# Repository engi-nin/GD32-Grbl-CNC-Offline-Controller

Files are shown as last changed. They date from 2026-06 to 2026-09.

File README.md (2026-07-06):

# GD32-Grbl-CNC-Offline-Controller

offline_F

## 概要
GD32F303VCT6を搭載した、ＧＲＢＬ‐ＣＮＣ向けのオフライン制御端末用ファームウェアです。

＊＊注意＊＊
GD32F303VCT6以外のマイコンやＴＦＴの種類によって正常に動かない可能性があります

GRBL1.1用のコントローラーとシリアル通信を行い、PCレスでの操作を実現します。
主な操作
ＸＹＺ軸のＪＯＧ操作、0.01,0.1,1,10mmの４段階、速度は５０ステップで５０～５００mm／min、スピンドルＯＮ、ＯＦＦ
＄コマンド出力、$H,$X$$,$C,$SLP,$G,$10,Ctrl+X
ＳＤカードからのファイル読み出し、Ｇコード出力、一時停止機能付き
ＸＹＺのゼロセット、ゼロ位置移動
プローブ動作、Ｚ、Ｘ＋、Ｘ－、Ｙ＋、Ｙ－、左下コーナーゼロセット、穴中心ゼロセット、軸中心ゼロセット

## ハードウェア仕様
- **MCU:** GD32F303VCT6
- **Display:** 1.8 inch TFT (ST7735)
- **Interface:** SPI / UART / SD Card

offline_B

### ピンアサイン（主要部分）
| 機能 | ピン番号 | 備考 |
タクトスイッチ
PB10(47)[OK]
PC4(33)[Y+]
PC6(63)[Y-]
PB12(51)[X+]
PB11(48)[X-]
PC5(35)[EXIT]
PB6(92)[Z+]
PB5(91)[Z-]

ＵＳＢ
PA11(70)USBDM
PA12(71)USBDP

SD SLOT
MOSI PB15(54)　　
MISO PB14(53) 　　
SD_SCK  PB13(52)  
CS_SLOT_A PC7(64)　　microSD
CS_SLOT_B PD12(59) 　ＳＤ

シリアル端子
PA2(25)USART_1TX
PA3(26)USART_1RX

(液晶表示はビットバンニングで動作確認できている)
1.8inchTFT

#define TFT_CS   PD7(88)　　チップセレクト
#define TFT_DC   PD11(58)　　データＨ／コマンドＬ切替
#define TFT_RST  PE1(90)　　リセット
#define TFT_WR   PD5(86)　　書き込み信号
#define TFT_RD   PD4(85)　　読み出し信号
#define TFT_BL   PD13(60) // バックライト
// データバス (D0-D7) の変則配置をここで定義
#define D0_PIN   PD14(61)　データビット０
#define D1_PIN   PD15(62)　データビット１
#define D2_PIN   PD0(81)　　データビット２
#define D3_PIN   PD1(82)　　データビット３
#define D4_PIN   PE7(38)　　データビット４
#define D5_PIN   PE8(39)　　データビット５
#define D6_PIN   PE9(40)　　データビット６
#define D7_PIN   PE10(41)　　データビット７

## 開発環境
- PlatformIO
- GD32 Arduino Core (または SPL)

## 使い方
1. PlatformIOでこのフォルダを開きます。
2. `platformio.ini` の設定を確認してください。
3. ビルドしてターゲットボードに書き込みます。

https://youtu.be/XpaJLY-EAXQ?si=iFZQxmoBzAtlG87i

## ライセンス
MIT License

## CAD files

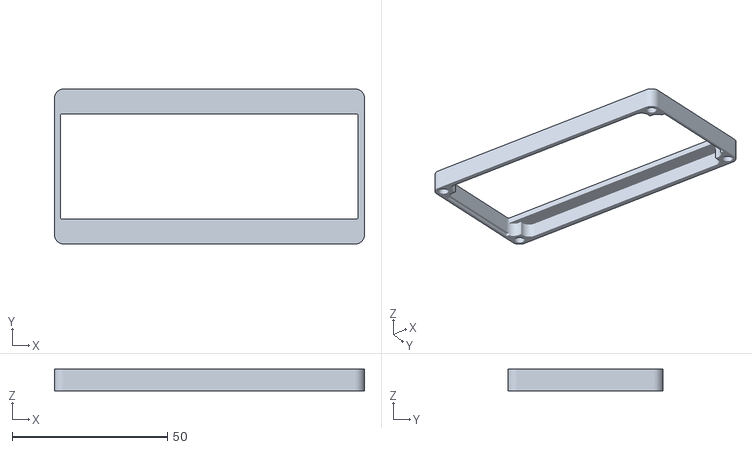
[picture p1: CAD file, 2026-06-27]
cad_data/upper case.stl
100.0 x 50.0 x 7.00

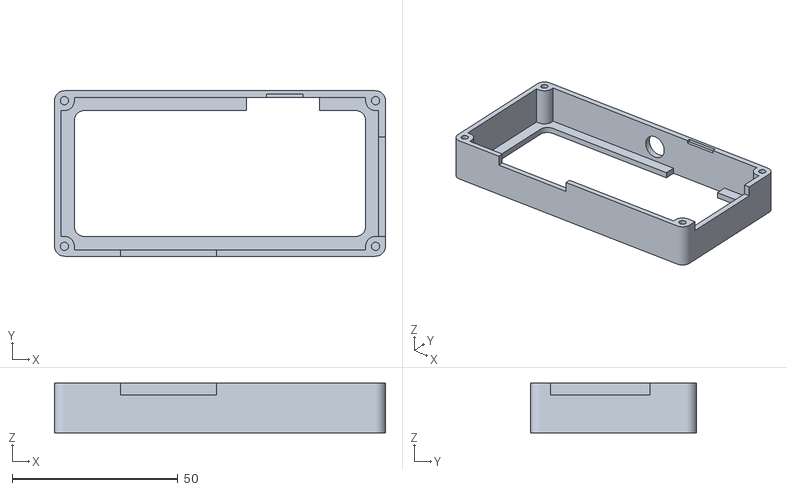
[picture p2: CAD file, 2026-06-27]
cad_data/under case.stl
100.0 x 50.0 x 15.0

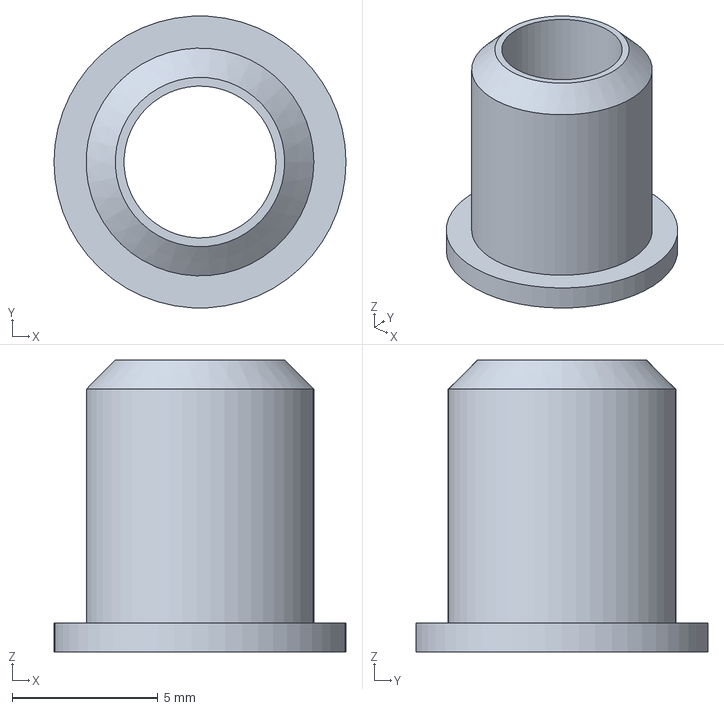
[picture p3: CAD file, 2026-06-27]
cad_data/cable_holder.FCStd
10.0 x 9.98 x 10.0 mm

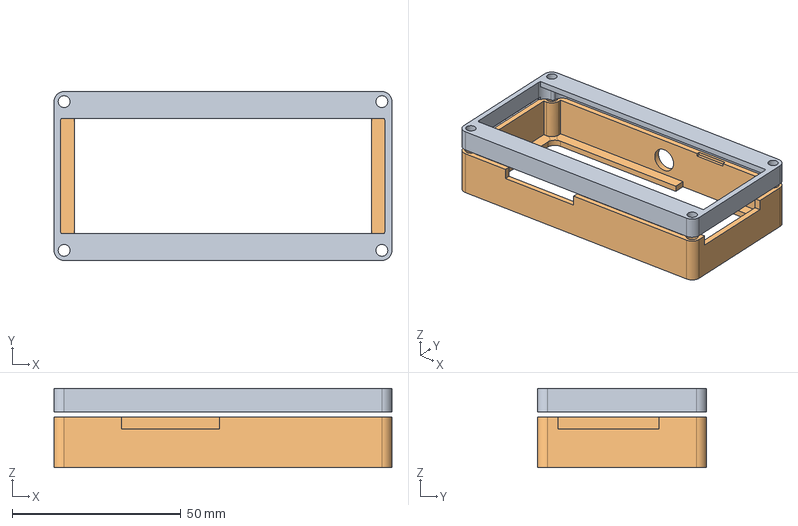
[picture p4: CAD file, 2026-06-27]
cad_data/offline_controller.FCStd
100.0 x 50.0 x 23.5 mm
upper case
under case

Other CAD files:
cad_data/cable_holder.stl

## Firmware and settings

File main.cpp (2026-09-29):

#include <Arduino.h>
#include "config.h"
#include "tft_control.h"
#include "switch_control.h"
#include "grbl_serial.h"
#include "sd_control.h"
#include <SPI.h>
#include <SdFat.h>
#include "probe_macro.h"


// --- 設定・定数 ---
#define BTN_W 20      // 標準の横幅
#define BTN_H 16      // 標準の高さ
#define BTN_R 5       // 角の丸み
#define BTN_Z_W 20    // Z軸などの細長いボタン用
#define ESC_BTN EXIT
#define OK_BTN OK
#define Y_PL   Y_UP // Ｙ＋
#define Y_DN   Y_DOWN  // Ｙ－
#define X_LF   X_DOWN  // Ｘ－
#define X_RT   X_UP  // Ｘ＋
#define Z_PL   Z_UP  // Ｚ＋
#define Z_DN   Z_DOWN  // Ｚ－
#define TFT_BL PD13
#define SD_CONFIG SdSpiConfig(PC7, SHARED_SPI, SD_SCK_MHZ(10), &softSpi)


// --- インスタンス ---
TFTControl tft;
SwitchControl sw;

SdFat fatFs;
FsFile currentGCodeFile;
SoftSpiDriver<PB14, PB15, PB13> softSpi;

//enum DisplayMode { MODE_MENU,MODE_JOG, MODE_SD, MODE_SETTING ,MODE_SENDING,MODE_PROBE};

struct JogButton {
    Button pin;        // スイッチのピン番号
    String axis;    // 軸名 ("X", "Y", "Z")
    float direction; // 向き (1.0 または -1.0)
    const char* label; // ボタンの表示名
    int16_t x, y, w, h; // 描画位置
    uint16_t color;  // 通常時の色
    int stateIdx;// lastStates配列の何番目を使うか
};

HardwareSerial SerialGrbl(PA3, PA2);

DisplayMode currentMode = MODE_MENU;

bool lastStates[6] = {false, false, false, false, false, false};
bool escLastState = false;
bool backLastState = false;
bool escIsBeingPressed = false;      // 今まさに押されているか
bool isEscLongTargetReached = false; // 長押し確定演出用
bool isFirstOpen = true; // 画面を開いた直後判定用
bool okIsBeingPressed = false;       // OKボタン状態
bool isSpindleOn = false;            // スピンドル状態
bool xUpLast = false, xDnLast = false;
bool yUpLast = false, yDnLast = false;
bool zUpLast = false, zDnLast = false;
bool xUpLastState = false;
bool xDnLastState = false;
bool yUpLastState = false;
bool yDnLastState = false; 
bool zUpLastState = false;
bool zDnLastState = false;
bool isSending = false;        // 送信中フラグ
bool isConfirming = false;
bool isStreaming = false;       // 送信中かどうかのフラグ
bool waitingForOk = false; // GRBLからの返答待ちフラグ
bool isWaitingInitialResponse = false; // 最初のリプライ待ちフラグ
bool isShowingConsole = false;
bool isMovingToZero = false; // 💡 ゼロ位置への移動中かどうかを保持するフラグ

uint32_t streamStartTime = 0;          // タイムアウト監視用
char lastError[32] = "";       // エラーメッセージ格納用
SdFile gcodeFile;              // 現在開いているGコードファイル
unsigned long escPressStartTime_ex = 0; // 押し始めた時刻
unsigned long escPressStartTime_xl = 0;
unsigned long escPressStartTime_xr = 0;
unsigned long escPressStartTime_zu = 0;
unsigned long escPressStartTime_zd = 0;

float moveDistance = 1.0;            // 現在の移動距離 (1mm, 10mmなど)
float curX, curY, curZ;
int moveSpeed = 100;                 // 初期送り速度 100
unsigned long okPressStartTime = 0;  // OKボタン用
uint32_t totalFileBytes = 0;    // ファイルの総サイズ
uint32_t sentFileBytes = 0;     // 送信済みのサイズ
char lastSentGCode[64] = "";    // 最後に送った行
char lastGrblResponse[64] = ""; // GRBLからの最後の返事
static char currentFileName[32]; // 選択されたファイル名を保持する配列
char lineBuffer[64]; // Gコード1行分を溜めるバッファ（CNCの1行は通常50文字程度なので64で十分です）
int lineIdx = 0;     // バッファのどこまで文字を入れたかを記録する添え字
int consoleLineY = 20; // ログの書き出し開始位置
static int consoleLineCount = 0; 

static int currentLogPage = 0;
static int totalCapturedLines = 0;
bool escHandled_ex = false;
bool escHandled_xl = false;
bool escHandled_xr = false;
bool escHandled_zu = false;
bool escHandled_zd = false;

int currentPage = 0;          // 現在のページ番号（0から開始）

// 設定項目の構造体定義
struct SettingItem {
    const char* name;    // 画面に表示する名前
    const char* command; // GRBLに送るコマンド
};
enum LogType { TYPE_ERROR, TYPE_ALARM, TYPE_HOLD, TYPE_DOOR, TYPE_INFO };

struct GrblLog {
    LogType type;
    int code;
    const char* msg; // メッセージの要約（任意）
};

static uint32_t lastUpdateMillis = 0;

// --- ここに項目を追加・削除するだけでメニューが増えます ---
const SettingItem SETTINGS[] = {
    {"Homing Start ($H)",     "$H"},
    {"Alarm Unlock ($X)",     "$X"},
    {"GrblConfig ($$)",     "$$"},
    {"Check Mode ($C)", "$C"},
    {"Sleep mode ($SLP)",    "$SLP"},
    {"Status Read ($G)",     "$G"},
    {"<WPos:> ($10=0)",       "$10=0"},   
    {"<MPos:> ($10=1)",         "$10=1"},     
    {"Soft Reset (Ctrl+X)",   "SoftRESET"}  // 特殊処理用にキーワードを定義
};

// 項目の総数を自動計算
const int TOTAL_SETTINGS = sizeof(SETTINGS) / sizeof(SETTINGS[0]);
String grblResponse = "";    // 受信した返答を格納
bool pendingResponse = false; // 返答待ちフラグ

int selectedIndex = 0;       // 現在選択されている番号
bool enterLastState = false; // 決定ボタンの状態保存用
bool upLastState    = false; // 上ボタンの状態保存用
bool downLastState  = false; // 下ボタンの状態保存用

extern void rawUartPrint(USART_TypeDef *uart, const char* s);

extern void rawUartWriteChar(USART_TypeDef *uart, char c);
extern void rawUartFlush(USART_TypeDef *uart);
extern bool rawUartAvailable(USART_TypeDef *uart);
extern char rawUartReadChar(USART_TypeDef *uart);
extern int rawUartRead(USART_TypeDef *uart);
extern void sendByte(uint8_t b);

void drawJogUI();
void drawSDFileListUI();
void drawMenuUI();
void drawSettingUI();
void updateStatusDisplay();
void updateDebugConsole(String msg);
bool startGCodeStream(const char* filename);
void ConsoleLog(const char* log, uint16_t color, int16_t x, int16_t y);
void drawProbeUI();
static float countX = 0.00f;
static float countY = 0.00f;
static float countZ = 0.00f;
// 送信を許可するコマンドのリスト（ホワイトリスト）
const char* whiteList[] = {
    "G0", "G1", "G2", "G3", "G17", "G20", "G21", "G90", "G91", "G54",
    "M2","M3", "M5", "M8", "M9", "M30", "S", "F", "$"
};
void stopGCodeStream();
bool isAllowed(const char* line);
void GrblCurrentPos();
bool isPaused = false;
static uint32_t lastOkTime = 0;

// ボタンの「役割」を定義
enum ButtonType {
    BTN_PRIMARY,   // 標準ボタン
    BTN_ENABLED,    // 決定ボタン
    BTN_SEND,   // 完了・実行
    BTN_DISABLED   // 無効状態（グレー）
};

// 色の管理用構造体
struct ButtonStyle {
    uint16_t body;
    uint16_t text;
};

// 役割に応じた色の設定（ここで一元管理！）
ButtonStyle getStyle(ButtonType type) {
    switch (type) {
        case BTN_PRIMARY:  return {0x64D9, 0xFFFF};
        case BTN_ENABLED:  return {0xF800, 0xFFFF};
        case BTN_SEND:     return {0xFFE0, 0xFFFF};
        case BTN_DISABLED: return {0x01AD, 0xFFFF}; // ダークグレーとライトグレー
        default:           return {0xFFFF, 0x0000};
    }
}

// GRBLから取得した実座標格納用
float prbX = 0.0f, prbY = 0.0f, prbZ = 0.0f;

// 内径測定用のステップ管理と一時記憶
static float center_X1 = 0.0f;
static float center_X2 = 0.0f;
static float center_Y1 = 0.0f;
static float center_Y2 = 0.0f;
static float target_X_Center = 0.0f;
static float target_Y_Center = 0.0f;

// ─── ファイルスコープ（またはグローバル）で維持する変数群 ───
static float macroStart_X = 0.0f;
static float macroStart_Y = 0.0f;
static float macroStart_Z = 0.0f;
static float calculated_X_Center = 0.0f;
static float calculated_Y_Center = 0.0f;

// 各測定ステップで取得するプローブ座標（PRB応答から抽出）

static float center_Z1 = 0.0f;
static float center_Z2 = 0.0f;

static float corner_X1 = 0.0f;
static float corner_Y1 = 0.0f;


// ─── 選択型メニュー用の管理変数 ───
int menuCursorX = 0; // 0:左列(アクション), 1:右列(モード遷移)
int menuCursorY = 0; // 0〜2行目 (左:X/Y, Z, 空き / 右:JOG, SD, SETTING, Probe)

// 長押しポップアップ管理用
bool isPopupActive = false;
int popupSelection = 0; // ポップアップ内の選択肢 (0: ゼロセット, 1: ゼロへ移動, 2: キャンセル)
int targetAxisMode = 0; // 0: X/Y軸, 1: Z軸

// ボタンの配置定義を扱いやすくするための構造体
struct MenuButtonPos {
    int x; int y; int w; int h;
    const char* label;
};

// 画面のボタン配置と完全に同期した配列
static const MenuButtonPos leftMenuBtns[2] = {
    {5,  38, 70, 18, "X/Y ZERO"},
    {5, 110, 70, 18, "Z ZERO"} 
};

static const MenuButtonPos rightMenuBtns[4] = {
    {85,  38, 65, 18, "JOG MODE"},
    {85,  62, 65, 18, "SD FILES"},
    {85,  85, 65, 18, "SETTINGS"},
    {85, 110, 65, 18, "Probe"}
};

// 内径探査のステート追跡用
enum DummyState { STATE_NONE, STATE_X1, STATE_X2, STATE_Y1, STATE_Y2,STATE_Z1,STATE_Z2,STATE_CR_X,STATE_CR_Y };

static const char* dummyZ_P1  = "D_Z_P1";
static const char* dummyZ_P2  = "D_Z_P2";

static const char* dummyX_P   = "D_X_P";
static const char* dummyX_M   = "D_X_M";
static const char* dummyY_P   = "D_Y_P";
static const char* dummyY_M   = "D_Y_M";

static const char* dummyCR_X1 = "D_CR_X1"; // コーナー用：X探査
static const char* dummyCR_X2 = "D_CR_X2"; // コーナー用：X退避(絶対座標)
static const char* dummyCR_Y1 = "D_CR_Y1"; // コーナー用：Y回り込み位置(絶対座標)
static const char* dummyCR_Y2 = "D_CR_Y2"; // コーナー用：ワーク前方に進む(絶対座標)
static const char* dummyCR_Y3 = "D_CR_Y3"; // コーナー用：Y探査
static const char* dummyCR_G10= "D_CR_G10";// コーナー用：最終座標設定＆安全退避

static const char* dummyIN_X1 = "D_IN_X1";
static const char* dummyIN_X2 = "D_IN_X2";
static const char* dummyIN_CX = "D_IN_CX";
static const char* dummyIN_Y1 = "D_IN_Y1";
static const char* dummyIN_Y2 = "D_IN_Y2";
static const char* dummyIN_CY = "D_IN_CY";

static const char* dummyOUT_X1 = "D_OUT_X1";
static const char* dummyOUT_X2 = "D_OUT_X2";
static const char* dummyOUT_X3 = "D_OUT_X3";
static const char* dummyOUT_X4 = "D_OUT_X4";
static const char* dummyOUT_X5 = "D_OUT_X5";
static const char* dummyOUT_Y1 = "D_OUT_Y1";
static const char* dummyOUT_Y2 = "D_OUT_Y2";
static const char* dummyOUT_Y3 = "D_OUT_Y3";
static const char* dummyOUT_Y4 = "D_OUT_Y4";
static const char* dummyOUT_Y5 = "D_OUT_Y5";
static const char* dummyOUT_FIN= "D_OUT_FIN";

bool isEditingWorkDia = false;  // ★追加：ワーク径のポップアップ表示/編集フラグ
int pendingProbeItem = 0;       // ★追加：ポップアップを開いた元のプローブ項目を一時保持
float workDiameter = 50.0f;     // ★追加：ワーク/穴の直径 (初期値)


// ボタンのラベルを描画するヘルパー関数
void drawButtonLabel(int16_t x, int16_t y, int16_t w, int16_t h, const char* label, uint16_t textColor) {
    tft.setTextColor(textColor);
    tft.setTextSize(1); 

    // --- 中央配置のための計算 ---
    // 標準フォント（Size 1）は 1文字 = 幅6px, 高さ8px です
    int16_t textWidth = strlen(label) * 6;
    int16_t textHeight = 8;

    // ボタンの幅(w)から文字の幅を引いて半分にすることで、正確に中央へ配置
    int16_t textX = x + (w - textWidth) / 2;
    int16_t textY = y + (h - textHeight) / 2;

    // もし計算結果がマイナス（ボタンより文字が長い）になった場合の安全策
    if (textX < x) textX = x + 2; 

    tft.setCursor(textX, textY);
    tft.print(label);
}
//ボタン描画
void drawMyButton(int16_t x, int16_t y, int16_t w, int16_t h, const char* label, ButtonType type) {
    // getStyleに引数で受け取った「type」を渡す
    ButtonStyle style = getStyle(type);
    
    tft.fillRoundRect(x, y, w, h, BTN_R, style.body);
    drawButtonLabel(x, y, w, h, label, style.text);
}
//起動時のロゴ画面
void drawOpeningScreen() {
    tft.fillScreen(0x0000); // 黒背景
    
    tft.setTextSize(2);
    
    tft.setTextColor(0x065F);
    tft.setCursor(60, 15);
    tft.print(F("Grbl"));
    tft.setCursor(40, 40);
    tft.setTextColor(0xEFFD);
    tft.print(F("OFFLINE"));
    tft.setCursor(20, 65);
    tft.print(F("CONTROLLER"));

    tft.setTextColor(0xFFFF);
    tft.setTextSize(1);
    tft.setCursor(60, 90);
    tft.print(F(VERSION_STR));
    
    //tft.update();
    delay(3000); // 2秒間ロゴを表示
}
//メニューコンソール用エラーコード表示データ
void drawDetailedLog(const char* rawRes, int16_t x, int16_t y) {
    LogType type = TYPE_INFO;
    int code = -1;
    uint16_t color = 0xFFFF; // デフォルト白
    String displayMsg = "";

    // --- 1. 種類の判定と解析 ---
    if (strstr(rawRes, "error:") != NULL) {
        type = TYPE_ERROR;
        code = atoi(rawRes + 6); // "error:" の後を取得
        color = 0xF800; // 赤
        displayMsg = "ERROR [" + String(code) + "]: ";
    } 
    else if (strstr(rawRes, "ALARM:") != NULL) {
        type = TYPE_ALARM;
        code = atoi(rawRes + 6);
        color = 0xFB20; // オレンジ
        displayMsg = "ALARM [" + String(code) + "]: ";
    }
    else if (strstr(rawRes, "Hold:") != NULL) {
        type = TYPE_HOLD;
        code = atoi(rawRes + 5);
        color = 0xFFE0; // 黄
        displayMsg = "HOLD [" + String(code) + "]: ";
    }
    else if (strstr(rawRes, "Door:") != NULL) {
        type = TYPE_DOOR;
        code = atoi(rawRes + 5);
        color = 0x07FF; // 水色
        displayMsg = "DOOR [" + String(code) + "]: ";
    }

    // --- 3. TFTへ表示 ---
    if (displayMsg != "") {
        ConsoleLog(displayMsg.c_str(), color, x, y);
    }
}
//コンソールエラー表示
void ConsoleLog(const char* log, uint16_t color, int16_t x, int16_t y) {
    tft.fillRect(x,y,150,8,0x0000);
    tft.setTextSize(1);
    tft.setTextColor(color); 
    tft.setCursor(x, y); 
    tft.print(log);
}
//メニュー画面ＸＹＺ描画
void updateMenuCoordinates() {
    // 通信確認
    bool isTimeout = (millis() - lastUpdateMillis > 1000);
    uint16_t txtColor = isTimeout ? 0xF800 : 0xFFFF;

    // X軸
    tft.setCursor(28, 65);
    tft.setTextColor(txtColor, 0x0000);
    if (!isTimeout) tft.print(String(grbl.currentX, 2)); 
    else tft.print("  ?.??");

    // Y軸
    tft.setCursor(28, 80);
    tft.setTextColor(txtColor, 0x0000);
    if (!isTimeout) tft.print(String(grbl.currentY, 2)); 
    else tft.print("  ?.??");

    // Z軸
    tft.setCursor(28, 95);
    tft.setTextColor(txtColor, 0x0000);
    if (!isTimeout) tft.print(String(grbl.currentZ, 2)); 
    else tft.print("  ?.??");
}
//ＸＹＺ位置取得
void GrblCurrentPos(int16_t x,int16_t y){
    grbl.sendByte('?');
    grbl.update(); 
        while (grbl.grblavailable()) {
        const char* res = grbl.getNextLine();
        
        if (res[0] == '<') {
            // ★重要：ここで解析関数を呼ぶ
            if (grbl.parseGrblResponse(res)) {
                lastUpdateMillis = millis(); // 座標解析に成功したらタイマーリセット
            }
        } 
        else if (strcmp(res, "ok") != 0) {
            // ok 以外の重要なメッセージ（error等）があればログへ
          drawDetailedLog(res,x,y);  
        }
    }
}
// 2. メインメニュー画面
void drawMenuUI() {
    grbl.clearBuffer();

    tft.fillScreen(0x0000); // 背景ブラック
    
    tft.setCursor(40, 5);
    tft.setTextColor(0xFFFF); // ホワイト
    tft.println(F("[ Main MENU ]"));
     
    // --- 座標表示エリアの背景と枠線 ---
    tft.fillRect(5, 20, 150, 15, 0x0000); // レスポンスコンソール背景
    tft.drawRect(5, 20, 150, 15, 0xFFFF); // レスポンスコンソール白い枠線
    tft.drawRect(5, 60, 75, 47, 0xFFFF); // ＸＹＺ Ａｘｉｓ白枠

    tft.setTextSize(1);
    tft.setTextColor(0xFFFF);
    
    GrblCurrentPos(10, 25);
    
    // X軸
    tft.setCursor(10, 65);
    tft.setTextColor(0xFFFF, 0x0000);
    tft.print("X:");
    tft.setCursor(28, 65);
    tft.print(String(grbl.currentX, 2));

    // Y軸
    tft.setCursor(10, 80);
    tft.setTextColor(0xFFFF, 0x0000);
    tft.print("Y:");
    tft.setCursor(28, 80);
    tft.print(String(grbl.currentY, 2));

    // Z軸
    tft.setCursor(10, 95);
    tft.setTextColor(0xFFFF, 0x0000);
    tft.print("Z:");
    tft.setCursor(28, 95);
    tft.print(String(grbl.currentZ, 2));
   
    // ==================================================
    // --- 十字キー選択対応：左列ボタンの配置 (menuCursorX == 0) ---
    // ==================================================
    for (int i = 0; i < 2; i++) {
        // ポップアップが閉じており、且つカーソルが左列(0)のi行目にある場合は ENABLED、それ以外は PRIMARY
        ButtonType btnType = (!isPopupActive && menuCursorX == 0 && menuCursorY == i) ? BTN_PRIMARY : BTN_DISABLED;
        
        drawMyButton(
            leftMenuBtns[i].x, 
            leftMenuBtns[i].y, 
            leftMenuBtns[i].w, 
            leftMenuBtns[i].h, 
            leftMenuBtns[i].label, 
            btnType
        );
    }

    // ==================================================
    // --- 十字キー選択対応：右列ボタンの配置 (menuCursorX == 1) ---
    // ==================================================
    for (int i = 0; i < 4; i++) {
        // ポップアップが閉じており、且つカーソルが右列(1)のi行目にある場合は ENABLED、それ以外は PRIMARY
        ButtonType btnType = (!isPopupActive && menuCursorX == 1 && menuCursorY == i) ? BTN_PRIMARY : BTN_DISABLED;
        
        drawMyButton(
            rightMenuBtns[i].x, 
            rightMenuBtns[i].y, 
            rightMenuBtns[i].w, 
            rightMenuBtns[i].h, 
            rightMenuBtns[i].label, 
            btnType
        );
    }
   
    grbl.clearBuffer();
}
//メニュー画面のＺボタンのポップアップ描画
void drawZeroPopup(const char* title) {
    // ポップアップの外枠と背景
    tft.fillRect(15, 35, 130, 80, 0x0000); // 黒塗り潰し
    tft.drawRect(15, 35, 130, 80, 0xF800); // 赤い警告枠
    
    tft.setCursor(25, 42);
    tft.setTextColor(0xFFFF);
    tft.print(title);
    
    // 選択肢の描画
    const char* options[3] = {
        " 1. Zero Set (G10)",
        " 2. Move to Zero",
        " 3. Cancel"
    };
    
    for (int i = 0; i < 3; i++) {
        tft.setCursor(20, 60 + (i * 15));
        if (popupSelection == i) {
            tft.setTextColor(0x0000, 0xFFFF); // 反転表示（選択中）
        } else {
            tft.setTextColor(0xFFFF, 0x0000);
        }
        tft.println(options[i]);
    }
}
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
void loop() {
   
    switch (currentMode) {
        case MODE_MENU:    handleMenuButtons();    break;
        case MODE_JOG:     handleJogButtons();    break;
        case MODE_SD:      handleSDButtons();     break;
        case MODE_SETTING: handleSettingButtons(); break;
        case MODE_SENDING: handleSendingMode();    break;
        case MODE_PROBE:   handleProbeButtons(); break;
    }
    handleProbeStreaming();
}

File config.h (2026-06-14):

#ifndef CONFIG_H
#define CONFIG_H

#include <Arduino.h>

// =================================================================
// 1. システム・バージョン情報
// =================================================================
const char* const VERSION_STR = "Ver 1.0";

// =================================================================
// 2. 物理ピン配置 (Pin Assignments)
// =================================================================
#define TFT_BL         PD13    // TFT バックライトピン

// ソフトSPI (SDカード用) ピン配置
#define SD_MOSI_PIN    PB15
#define SD_MISO_PIN    PB14
#define SD_SCK_PIN     PB13
#define SD_CS_PIN      PC7

// GRBLシリアル通信ピン (HardwareSerial)
#define GRBL_TX_PIN    PA2
#define GRBL_RX_PIN    PA3

// =================================================================
// 3. キー入力・ボタンマッピング設定
// =================================================================
#define ESC_BTN        EXIT    // 物理スイッチのキャンセル割り当て
#define OK_BTN         OK      // 物理スイッチの決定割り当て

#define Y_PL           Y_UP    // Ｙ＋方向ボタン
#define Y_DN           Y_DOWN  // Ｙ－方向ボタン
#define X_LF           X_DOWN  // Ｘ－方向ボタン
#define X_RT           X_UP    // Ｘ＋方向ボタン
#define Z_PL           Z_UP    // Ｚ＋方向ボタン
#define Z_DN           Z_DOWN  // Ｚ－方向ボタン

const int LONG_PRESS_MS = 800;        // 長押しと判定する時間（ミリ秒）
const unsigned long LONG_PRESS_TIME = 1000; // ポップアップ等での長押し確定時間

// =================================================================
// 4. UI・グラフィックデザイン定数
// =================================================================
#define BTN_W          20      // 標準のボタン横幅
#define BTN_H          16      // 標準のボタン高さ
#define BTN_R          5       // ボタン角の丸み
#define BTN_Z_W        20      // Z軸等の細長いボタン用横幅

const int ITEMS_PER_PAGE = 10; // SDカード等の1画面あたり最大表示数
const int lineHeight     = 10; // コンソールログの1行の高さ
const int logStartX      = 5;  // ログの描画開始X座標
const int logStartY      = 18; // ログの描画開始Y座標
enum DisplayMode { MODE_MENU,MODE_JOG, MODE_SD, MODE_SETTING ,MODE_SENDING,MODE_PROBE};
// =================================================================
// 5. CNC・プローブ（探査）初期設定パラメータ
// =================================================================
const float DEFAULT_TOOL_DIAMETER = 3.0f;  // デフォルトのツール径 (mm)
const float DEFAULT_PROBE_FEEDRATE = 40.0f; // タッチ探査時のフィードスピード (F)

// 外径・内径探査の安全逃げ・潜り設定
const float DEFAULT_OUTER_CLEARANCE_X = 40.0f; // 開始点から左右に逃げる距離 (mm)
const float DEFAULT_OUTER_CLEARANCE_Y = 40.0f; // 開始点から前後に逃げる距離 (mm)
const float DEFAULT_OUTER_PROBE_DEPTH = 15.0f; // タッチのためにZ軸が潜る深さ (mm)


#endif // CONFIG_H

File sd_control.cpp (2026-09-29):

#include <SdFat.h>
#include "sd_control.h"

extern SoftSpiDriver<PB14, PB15, PB13> softSpi; 

SDControl::SDControl() : _fileCount(0), _selectedIndex(0), _currentSlot(SLOT_A), _isInitializedA(false), _isInitializedB(false) {
    _currentSD = &_sdA; 
}

void SDControl::releaseAllSlots() {
    pinMode(CS_SLOT_A, OUTPUT);
    pinMode(CS_SLOT_B, OUTPUT);
    digitalWrite(CS_SLOT_A, HIGH);
    digitalWrite(CS_SLOT_B, HIGH);
}
    
void SDControl::activateBus() {
    releaseAllSlots();
    delayMicroseconds(10); 
}

bool SDControl::_initBus(SDSlot slot, bool forceReinit) {
    _currentSD = (slot == SLOT_A) ? &_sdA : &_sdB;

    // ファイルが開いているなら閉じる
    if (_currentFile.isOpen()) {
        _currentFile.close();
    }

    releaseAllSlots();
    delay(20); 

    uint8_t targetPin = (slot == SLOT_A) ? CS_SLOT_A : CS_SLOT_B;
 
    // 安定性を考慮し、2MHzで初期化
    SdSpiConfig config(targetPin, SHARED_SPI, SD_SCK_MHZ(2), &softSpi);
    
    // 毎回 .end() を呼んでバスの競合を防ぐ
    _currentSD->end();
    
    // フラグでスキップせず、毎回確実に begin() を通す
    // (SdFatの begin() は安全に再初期化を行ってくれます)
    if (!_currentSD->begin(config)) {
        if (slot == SLOT_A) _isInitializedA = false;
        else _isInitializedB = false;
        return false; 
    }

    if (slot == SLOT_A) _isInitializedA = true;
    else _isInitializedB = true;

    _currentSlot = slot;
    return true;
}

bool SDControl::scanFiles(SDSlot slot) {
    _fileCount = 0;
    _selectedIndex = 0;
    for (int i = 0; i < MAX_FILES; i++) _fileList[i][0] = '\0';

    // スロットを切り替えて初期化
    if (!_initBus(slot, false)) {
        return false; 
    }

    FsFile root;
    // 修正: _currentSD->open() を使用してルートディレクトリを開く
    if (!root.open(_currentSD->vol(), "/", O_RDONLY)) { 
        // ボリューム指定でのオープンが失敗する場合のフォールバック
        if (!root.open(_currentSD, "/", O_RDONLY)) {
            return false;
        }
    }

    FsFile entry;
    while (entry.openNext(&root, O_RDONLY)) {
        if (!entry.isDir() && !entry.isHidden()) {
            entry.getName(_fileList[_fileCount], sizeof(_fileList[0]));
            _fileCount++;
        }
        entry.close();
        if (_fileCount >= MAX_FILES) break;
    }
    root.close();

    if (_fileCount == 0) {
        cid_t cid;
        return _currentSD->card()->readCID(&cid);
    }
    return true;
}

void SDControl::selectNext() {
    if (_fileCount > 0) _selectedIndex = (_selectedIndex + 1) % _fileCount;
}

void SDControl::selectPrev() {
    if (_fileCount > 0) _selectedIndex = (_selectedIndex - 1 + _fileCount) % _fileCount;
}

char* SDControl::getSelectedFileName() {
    if (_fileCount == 0) return nullptr;
    return _fileList[_selectedIndex];
}

uint32_t SDControl::getFileSize() {
    if (_currentFile.isOpen()) {
        return _currentFile.size();
    }
    return 0;
}

bool SDControl::openFile(const char* filename) {
    if (_currentFile.isOpen()) {
        _currentFile.close();
    }
    
    // スロットのバスと初期化状態を確認
    if (!_initBus(_currentSlot, false)) return false;

    // 修正: _currentSD のオブジェクトから直接 open する
    _currentFile = _currentSD->open(filename, O_RDONLY);
    
    return _currentFile.isOpen();
}

void SDControl::closeCurrent() {
    if (_currentFile.isOpen()) {
        _currentFile.close();
    }
}

const char* SDControl::getCurrentSlotName() {
    return (_currentSlot == SLOT_A) ? "Slot A" : "Slot B"; 
}

bool SDControl::switchSlot() {
    SDSlot nextSlot = (_currentSlot == SLOT_A) ? SLOT_B : SLOT_A;
    return scanFiles(nextSlot);
}

bool SDControl::toggleSlotAndScan() {
    return switchSlot();
}

// ==========================================
// 💡 安全なファイル操作ラッパー
// ==========================================

int SDControl::readChar() {
    if (_currentFile && _currentFile.isOpen()) {
        return _currentFile.read();
    }
    return -1;
}

int SDControl::availableBytes() {
    if (_currentFile && _currentFile.isOpen()) {
        return _currentFile.available();
    }
    return 0;
}

SDControl sdCtrl;

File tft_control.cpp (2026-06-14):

// tft_control.cpp
#include "tft_control.h"
// ピン定義
#undef TFT_CS
#define TFT_CS PD7
#undef TFT_DC
#define TFT_DC PD11
#undef TFT_RST
#define TFT_RST PE1
#undef TFT_WR
#define TFT_WR PD5
#undef TFT_RD
#define TFT_RD PD4
#undef TFT_BL
#define TFT_BL PD13

// 液晶への1バイト書き込み (8bitパラレル) - 通信の核
void TFTControl::writeBusFast(uint8_t val) {
    uint32_t d_bsrr = (val & 0x01) ? (1 << 14) : (1 << (14 + 16));
    d_bsrr |= (val & 0x02) ? (1 << 15) : (1 << (15 + 16));
    d_bsrr |= (val & 0x04) ? (1 << 0)  : (1 << (0 + 16));
    d_bsrr |= (val & 0x08) ? (1 << 1)  : (1 << (1 + 16));
    GPIOD->BSRR = d_bsrr;

    uint32_t e_bsrr = (val & 0x10) ? (1 << 7)  : (1 << (7 + 16));
    e_bsrr |= (val & 0x20) ? (1 << 8)  : (1 << (8 + 16));
    e_bsrr |= (val & 0x40) ? (1 << 9)  : (1 << (9 + 16));
    e_bsrr |= (val & 0x80) ? (1 << 10) : (1 << (10 + 16));
    GPIOE->BSRR = e_bsrr;

    GPIOD->BRR = (1 << 5); 
    __asm__("nop"); 
    GPIOD->BSRR = (1 << 5);
}

void TFTControl::tftbegin() {
    pinMode(TFT_CS, OUTPUT); pinMode(TFT_DC, OUTPUT);
    pinMode(TFT_RST, OUTPUT); pinMode(TFT_WR, OUTPUT);
    pinMode(TFT_RD, OUTPUT);// pinMode(TFT_BL, OUTPUT);
    
    pinMode(PD14, OUTPUT); pinMode(PD15, OUTPUT);
    pinMode(PD0,  OUTPUT); pinMode(PD1,  OUTPUT);
    pinMode(PE7,  OUTPUT); pinMode(PE8,  OUTPUT);
    pinMode(PE9,  OUTPUT); pinMode(PE10, OUTPUT);

    digitalWrite(TFT_CS, HIGH); digitalWrite(TFT_WR, HIGH);
    digitalWrite(TFT_RD, HIGH); //digitalWrite(TFT_BL, HIGH);

    digitalWrite(TFT_RST, LOW); delay(50);
    digitalWrite(TFT_RST, HIGH); delay(50);

    sendCmd(0x01); delay(150); // SW Reset
    sendCmd(0x11); delay(200); // Sleep Out
    sendCmd(0x3A); sendDat(0x05); // 16bit color
    sendCmd(0x36); sendDat(0x00); // 以前「赤くなった」時の値 (0x00 か 0x08)
    sendCmd(0x36); 
    sendDat(0xA8);//0xA8 0xC8 0x08
    setRotation(2);
    sendCmd(0x29); delay(50); // Display ON
      
}

void TFTControl::sendCmd(uint8_t cmd) {
    digitalWrite(TFT_DC, LOW); digitalWrite(TFT_CS, LOW);
    writeBusFast(cmd); digitalWrite(TFT_CS, HIGH);
}

void TFTControl::sendDat(uint8_t dat) {
    digitalWrite(TFT_DC, HIGH); digitalWrite(TFT_CS, LOW);
    writeBusFast(dat); digitalWrite(TFT_CS, HIGH);
}

// --- Adafruit_GFX用実装 ---

void TFTControl::drawPixel(int16_t x, int16_t y, uint16_t color) {
    if ((x < 0) || (x >= width()) || (y < 0) || (y >= height())) return;

    // 1. 座標を指定 (AddrWindow)
    sendCmd(0x2A); // CASET
    sendDat(x >> 8); sendDat(x & 0xFF); // Start X
    sendDat(x >> 8); sendDat(x & 0xFF); // End X

    sendCmd(0x2B); // RASET
    sendDat(y >> 8); sendDat(y & 0xFF); // Start Y
    sendDat(y >> 8); sendDat(y & 0xFF); // End Y

    // 2. 書き込み開始
    sendCmd(0x2C); // RAMWR
    digitalWrite(TFT_DC, HIGH);
    digitalWrite(TFT_CS, LOW);
    
    writeBusFast(color >> 8);
    writeBusFast(color & 0xFF);
    
    digitalWrite(TFT_CS, HIGH);
}

void TFTControl::fillScreen(uint16_t color) {
    // 1. 画面全体の範囲を指定 (0,0 から 159,127 まで)
    sendCmd(0x2A); // Column Address Set
    sendDat(0x00); sendDat(0x00);              // Start X: 0
    sendDat(0x00); sendDat(this->width() - 1); // End X: 159

    sendCmd(0x2B); // Row Address Set
    sendDat(0x00); sendDat(0x00);              // Start Y: 0
    sendDat(0x00); sendDat(this->height() - 1); // End Y: 127

    // 2. 書き込み開始コマンド
    sendCmd(0x2C); // Memory Write

    // 3. チップセレクトを下げて高速転送モードへ
    digitalWrite(TFT_DC, HIGH); 
    digitalWrite(TFT_CS, LOW);

    uint8_t hi = color >> 8;
    uint8_t lo = color & 0xFF;
    uint32_t numPixels = (uint32_t)TFT_WIDTH * TFT_HEIGHT;

    // バッファ配列を介さず、直接バスに流し込む
    for (uint32_t i = 0; i < numPixels; i++) {
        writeBusFast(hi);
        writeBusFast(lo);
    }

    digitalWrite(TFT_CS, HIGH);
}

void TFTControl::fillRect(int16_t x, int16_t y, int16_t w, int16_t h, uint16_t color) {
    // 範囲外チェックなどは省略
    
    // 1. 塗りつぶす範囲を指定
    sendCmd(0x2A); 
    sendDat(x >> 8); sendDat(x & 0xFF);
    sendDat((x + w - 1) >> 8); sendDat((x + w - 1) & 0xFF);

    sendCmd(0x2B);
    sendDat(y >> 8); sendDat(y & 0xFF);
    sendDat((y + h - 1) >> 8); sendDat((y + h - 1) & 0xFF);

    // 2. 連続書き込み
    sendCmd(0x2C);
    digitalWrite(TFT_DC, HIGH);
    digitalWrite(TFT_CS, LOW);

    uint8_t hi = color >> 8;
    uint8_t lo = color & 0xFF;
    uint32_t numPixels = (uint32_t)w * h;

    for (uint32_t i = 0; i < numPixels; i++) {
        writeBusFast(hi);
        writeBusFast(lo);
    }
    digitalWrite(TFT_CS, HIGH);
}

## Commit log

2026-06-22 Add files via upload
    プローブ時の逃げを１ｍｍに変更
2026-06-27 Add files via upload
    XY単独プローブの終了位置をツールの中心に変更
2026-09-29 Update main.cpp
    軽微な表示のバグ修正とＪＯＧ移動量のチャタリング修正
2026-09-29 Update grbl_serial.cpp
    不用になった関数の削除
2026-09-29 Update grbl_serial.h
    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
2026-09-29 Update sd_control.cpp
    ＳＤカードの読取り不良修正
